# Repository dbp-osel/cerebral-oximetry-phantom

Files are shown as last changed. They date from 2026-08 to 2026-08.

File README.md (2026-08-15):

# cerebral-oximetry-phantom
Title: Cerebral oximetry phantom module

Contains STL files for 3D printing of cerebrovascular modules - the main component for a published cerebral oximetry test method

Keywords: Phantom, Cerebral oximeter, NIRS, brain, Blood oxygen saturation

Description:
These cerebrovascular modules (CVM) were developed by Dr. Joshua Pfefer’s group in FDA as part of a phantom-based test method for evaluating of cerebral oximetry performance accuracy 

CVMs were fabricated using a stereolithography 3D‐printer (Form2, Formlabs, Inc., Somerville, MA, USA) based on UV-curing of customized methacrylate photopolymer resin composites well‐matched with human brain optical properties.  The CVMs were constructed with overall dimensions of 120 x 120 x 50 mm, with the perfused channel-array region limited to a volume of 120 x 80 x 32.5 mm with channel length of 106 mm in two forms (high and low ctHb levels by modifying the channel diameter) and adult/neonate by customizing the ratio of resins to represent optical preparties for the specified age range. CVMs incorporate a total of 119 cylindrical linear channels spaced 4.36 mm apart in the vertical and 4.58 – 4.6 mm horizontal directions, with the top row of channels (upper boundary of the channels) 1 mm below the phantom surface. Adult and neonatal CVMs with 75 µM ctHb levels had a nominal channel diameter of 1.12 mm, yet the mean measured channel diameter -  based on µCT images of a thin multi-channel sample and measuring volume of injected water to ten randomly selected channels - was 0.97 ± 0.04 mm (mean ± standard deviation). The nominal vs. measured channel dimeters for the 46 µM ctHb and 33 µM cases were: 0.90 mm vs. 0.71 mm; 0.80 mm vs. 0.60 mm respectively.  Two 3D-printed lids made of clear resin (120 x 50 x 10 mm) were also attached at the sides of CVM by screws to keep blood and minimize air exposure and subsequent reoxygenation of blood. Blood can be injected into the channels using a 60 ml syringe connected to a manifold in one of 3D-printed side lids to the CVM. 

Implemented - and described more thoroughly - in two published articles:

(use as primary attribution) Afshari A, Ghassemi P, Halprin M, Lin J, Wang J, Mendoza G, Weininger S, Pfefer TJ. Cerebral oximetry performance testing with a 3D-printed vascular array phantom. Biomed Opt Express, 10(8), 3731-3746, 2019. doi.org/10.1364/BOE.10.003731

Afshari A, Saager R, Burgos D, Vogt W, Wang J, Mendoza G, Weininger S, Sung KB, Durkin AJ, Pfefer TJ. Evaluation of the robustness of cerebral oximetry to variations in skin pigmentation using a novel tissue phantom.  Biomed Opt Express, 13(5):2909-2928, 2022. doi.org/10.1364/BOE.454020 

Model color: Monochrome
Model origin: Custom illustration/ CAD
License: CC BY
Medical application: Bioprinting or Tissue Fabrication
Prosthetic Type: None
Imaging modality: None
Diagnosis/ Condition: Cardiovascular
Institutional Affiliation: Food and Drug Administration (FDA), CDRH, OSEL, DBP

Recommended 3D Printer: stereolithography 3D‐printer
Recommended Printing Material: customized methacrylate photopolymer resin composites
Recommended Support Material: 
Finishing instruction: Performing a rough rinse in IPA, then a refining IPA rinse to remove residual resin, and then post process the dried part in a UV and thermal atmosphere. 

#
---

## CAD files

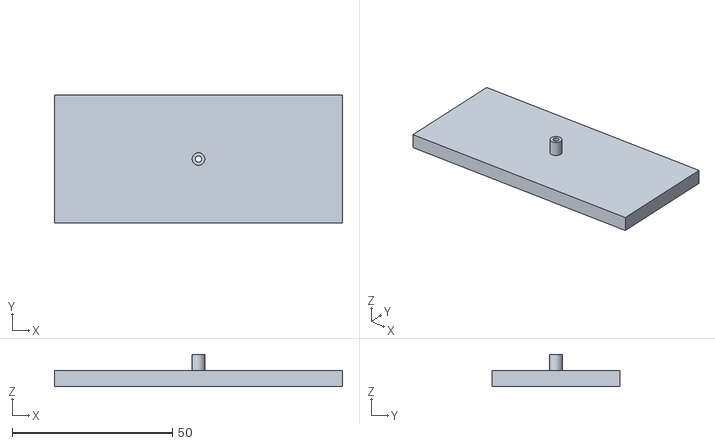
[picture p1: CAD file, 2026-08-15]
cap_with_hole.stl
90.0 x 40.0 x 10.0

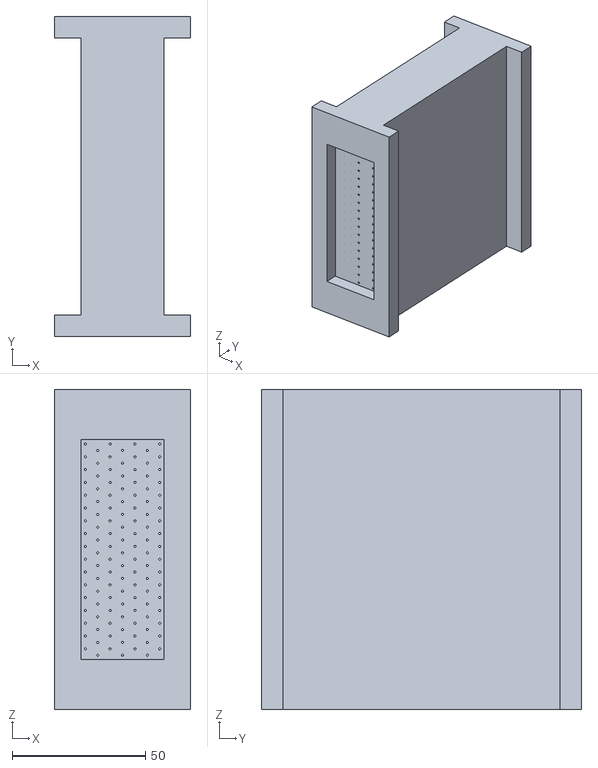
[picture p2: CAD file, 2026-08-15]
CVM1_0.8mm_33_ctHb.STL
51.0 x 120.0 x 120.0

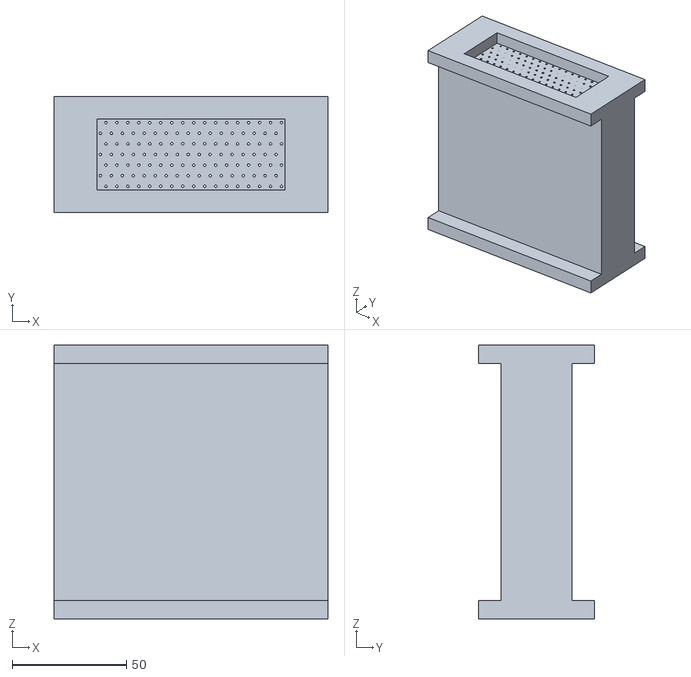
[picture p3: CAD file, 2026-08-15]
CVM3_1.12mm_75_ctHb.STL
120.0 x 51.0 x 120.0

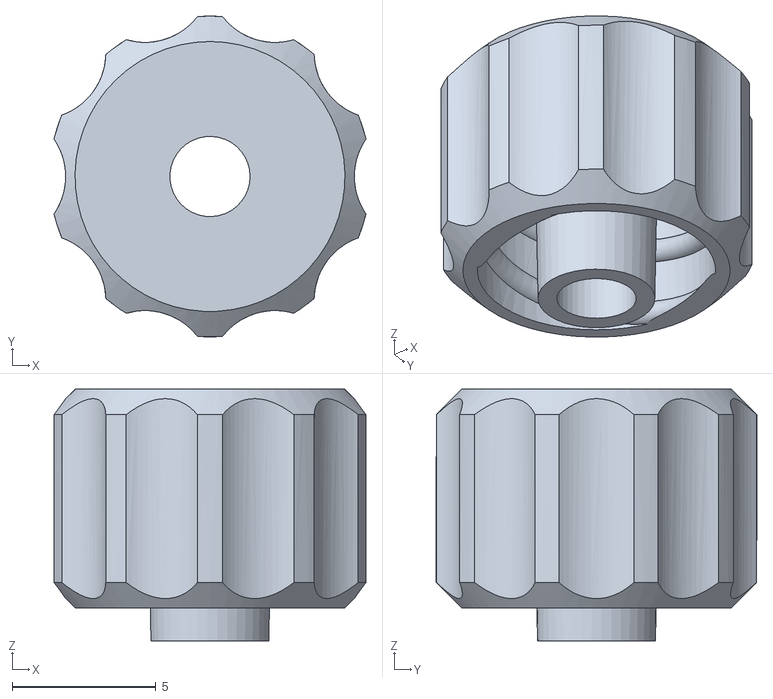
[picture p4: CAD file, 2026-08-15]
51525K241_caponly.STL
10.9 x 11.2 x 8.76

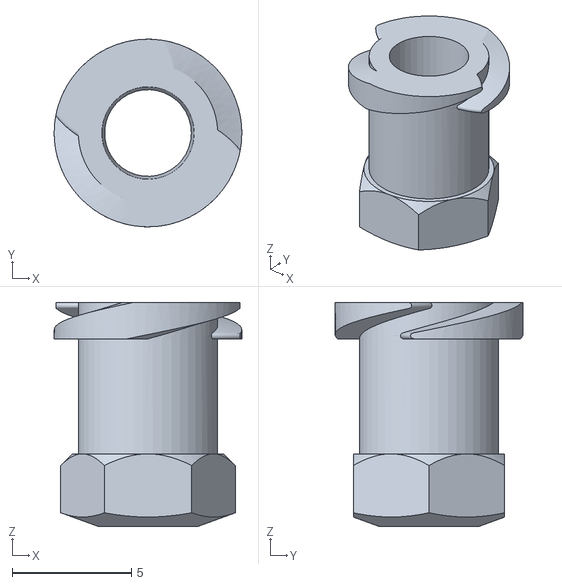
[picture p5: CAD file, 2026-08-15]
51525K222mod_COUPLING_jh051817.STL
7.87 x 7.87 x 9.40
